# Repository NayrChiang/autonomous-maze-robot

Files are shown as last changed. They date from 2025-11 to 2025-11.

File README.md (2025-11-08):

# Autonomous Maze Navigation Robot

A comprehensive autonomous robot system for maze navigation, localization, and block manipulation using Arduino, MATLAB, and probability-based algorithms. This project demonstrates integration of multiple sensors, real-time control, and autonomous decision-making in a complex environment.

## Project Overview

**Course**: MIE444 - Mechatronics  
**Institution**: University of Toronto  
**Term**: Fall 2022

### Objective

Design and build an autonomous robot capable of navigating a maze, localizing its position using probability-based algorithms, avoiding obstacles, detecting blocks, and manipulating objects to complete assigned tasks.

## Key Features

### Multi-Sensor Data Fusion
- **7 Ultrasonic Sensors (HC-SR04)**: Front, left, right, back, and 45° angle sensors for comprehensive obstacle detection
- **2 IR Sensors**: Block detection and floor pattern recognition for localization
- Multi-sample averaging (5 samples per reading) for noise reduction
- Real-time sensor data fusion for robust environment sensing

### Probability-Based Localization
- Monte Carlo localization algorithm in 32×16 grid maze (512 possible locations)
- IR sensor for color tile recognition
- Real-time position tracking with probability distribution updates
- 10% probability threshold for successful localization confirmation
- Heading initialization and correction at block 14 using unique distance patterns

### Autonomous Navigation
- Perfect obstacle avoidance with collision-free navigation
- Four heading directions (W, A, S, D) for 2D IR localization
- Angle correction logic comparing current and previous step sensor readings
- Wall distance thresholds: front (8cm), sides (4cm), back (5cm)
- Fixed path planning for 32 block locations with configurable loading/unloading sequences

### Block Detection and Manipulation
- Ultrasonic sensor scanning sequence (90-100° rotation in 5° increments)
- Detection criteria: Bottom sensor < 50 cm AND absolute difference between front and bottom sensor > 10 cm
- 3D-printed mechanical gripper controlled by two SG90 servo motors
- Joint servo for elevation control, jaw servo for opening/closing
- Pickup and delivery sequences with precise positioning

### MATLAB-Arduino Integration
- Real-time control via Bluetooth (HC-05, 9600 baud)
- Serial command protocol for motor and servo control
- Real-time probability distribution visualization
- Simplified testing and troubleshooting workflow

## Hardware Components

### Microcontrollers
- **Arduino Uno** (2 boards): Separate boards for sensors and motor/servo control

### Sensors
- **7× Ultrasonic Sensors (HC-SR04)**: Obstacle detection at multiple angles
- **2× IR Sensors**: Block detection and floor pattern recognition

### Actuators
- **DC Motors**: With H-bridge (L298N) for omnidirectional movement
- **2× Servo Motors (SG90)**: 
  - Gripper servo: Controls opening/closing (45-90°)
  - Lift servo: Controls elevation (20-140°)
- **Omni Wheels**: For omnidirectional movement

### Communication
- **HC-05 Bluetooth Module**: 9600 baud serial communication

### Chassis
- Custom 3D-printed design with integrated sensor mounts
- Redesigned from 9-inch to 6.5-inch diameter (top layer) for improved sensor accuracy
- Multi-layer assembly for component organization

## Software Architecture

### Arduino Firmware
- **Arduino_for_Sensors.ino**: Sensor data acquisition and processing
- **Arduino_for_Motor_&_Servo.ino**: Motor and servo control
- Serial command protocol for MATLAB communication

### MATLAB Control Algorithms
- **Matlab_Real_ObsAvoid_HeadingInit_LoadDropOffZone.m**: Main control algorithm
- **Matlab_Real_Block_Detection_PickUp.m**: Block detection and manipulation
- **Matlab_Simulator_ObsAvoid_HeadingInit_LoadDropOffZone.m**: Simulation for testing

### Key Algorithms
- Probability-based localization (Monte Carlo methods)
- Obstacle avoidance with angle correction
- Block detection using ultrasonic scanning
- Path planning and navigation

## Technical Implementation

### Sensor Integration
- Multi-sample averaging (5 samples) for noise reduction
- Distance calculation: ping time to distance (0.017 cm/μs)
- Sensor threshold calibration at various maze locations
- Multi-sensor data fusion for comprehensive environment sensing

### Obstacle Avoidance
- Four heading directions defined for 2D IR localization
- Angle correction logic: Comparison of current step (U3) and previous step (U3') side sensor readings
- If U3 < U3': Rotate counterclockwise to correct angle
- If U3 > U3': Rotate clockwise
- Perfect collision-free navigation achieved

### Localization
- Probability distribution initialization: uniform (1/512 per cell)
- Probability updates: Measurement compared with actual color tile map
- Probability threshold: 10% for confirmation of successful localization
- Threshold-based path switching: switches to fixed path when probability > 10%
- Heading management: Updated by adding/subtracting 90° when robot makes turns

### Block Manipulation
- Initial scan: Shifts left and right to check if block is in straight line of sight
- Detailed scan: 90-100° rotation in 5° increments once inside loading zone
- Pickup sequence: Abort rotation → Drive forward → Open and lower gripper → Close and raise
- Delivery: Navigate to unloading zone → Lower lift → Open gripper → Raise lift → Close gripper

## Project Structure

```
autonomous-maze-robot/
├── arduino-code/
│   ├── Arduino_for_Motor_&_Servo/
│   │   └── Arduino_for_Motor_&_Servo.ino
│   └── Arduino_for_Sensors/
│       └── Arduino_for_Sensors.ino
├── matlab-code/
│   ├── Matlab_Real_Block_Detection_PickUp/
│   │   └── Matlab_Real_Block_Detection_PickUp.m
│   ├── Matlab_Real_ObsAvoid_HeadingInit_LoadDropOffZone/
│   │   └── Matlab_Real_ObsAvoid_HeadingInit_LoadDropOffZone.m
│   └── Matlab_Simulator_ObsAvoid_HeadingInit_LoadDropOffZone/
│       └── Matlab_Simulator_ObsAvoid_HeadingInit_LoadDropOffZone.m
├── cad-models/
│   └── Rover 3D CAD Model/
│       ├── Rover.SLDASM
│       ├── Base - 7 in.SLDPRT
│       ├── Second - 7 in.SLDPRT
│       ├── Third - 7 in.SLDPRT
│       ├── Top Layer - 6 in.SLDPRT
│       └── [other component files]
├── MIE444 Project Final Report.pdf
└── README.md
```

## Installation & Setup

### Prerequisites
- Arduino IDE
- MATLAB (with Arduino Support Package)
- HC-05 Bluetooth module
- Required hardware components (see Hardware Components section)

### Hardware Setup
1. Assemble robot chassis according to CAD models
2. Install sensors and actuators
3. Connect Arduino boards and Bluetooth module
4. Power system setup

### Software Setup
1. Install Arduino IDE and required libraries
2. Upload sensor code to Arduino_for_Sensors board
3. Upload motor/servo code to Arduino_for_Motor_&_Servo board
4. Install MATLAB Arduino Support Package
5. Configure Bluetooth connection in MATLAB
6. Run MATLAB control scripts

## Usage

### Running the Robot
1. Power on both Arduino boards
2. Establish Bluetooth connection between MATLAB and HC-05 module
3. Run main MATLAB control script: `Matlab_Real_ObsAvoid_HeadingInit_LoadDropOffZone.m`
4. Monitor probability distribution and sensor readings in real-time
5. Robot will autonomously navigate, localize, and complete tasks

### Simulation
- Use `Matlab_Simulator_ObsAvoid_HeadingInit_LoadDropOffZone.m` for testing algorithms before real robot implementation
- Adjust sensor error settings for proof of concept testing

## Final Results

### Obstacle Avoidance
✅ **Met requirement**: Rover did not need human assistance, no wall collisions, made minor heading adjustments  
⚠️ **Trade-off**: Speed was slow due to accuracy trade-off, unable to complete all tasks within time limit

### Localization
✅ **Tested in demonstration**: Rover started at block 30 with heading ~170°, followed path to loading zone, arrived at block 1 (loading zone) within time constraint

### Block Detection
✅ **Functional**: Trial 2 - Rover placed at exterior of loading zone (block 17), successfully detected load at center of block 1

### Block Manipulation
⚠️ **Limited**: Detection logic functional, but pickup/delivery failed due to gripper design limitations:
- Insufficient torque (single 12V battery)
- Weak connection (press-fit enlarged after use)
- Size limitations (2.64 inches jaw distance)
- Motor drift during approach

## Key Achievements

- Successfully integrated 9 sensors (7 ultrasonic + 2 IR) with multi-sample averaging
- Implemented probability-based localization algorithm (Monte Carlo) with 10% threshold
- Developed autonomous navigation system with perfect obstacle avoidance
- Designed angle correction logic for accurate localization
- Achieved reliable block detection using ultrasonic sensor scanning
- Integrated MATLAB-Arduino system via Bluetooth for real-time control
- Implemented fixed path planning system for 32 block locations
- Successfully demonstrated localization and navigation in competition
- Designed and fabricated complete robot chassis using SolidWorks CAD
- Redesigned rover for improved sensor accuracy and performance

## Lessons Learned

- **Time Management**: Better allocation needed for rover design, sensor adjustment, and code integration
- **Gripper Design**: Increase size for tolerance, individual power supply for servos, more reliable connection method
- **Code Organization**: Version control (GitHub) would help with code merging and communication
- **Rover Design**: Initial 9-inch diameter had sensors too close to walls; redesign to 6.5-inch improved performance
- **Bluetooth Implementation**: Significant achievement - simplified testing and enabled simultaneous MATLAB/Arduino testing

## License

This project is licensed under the Apache License 2.0 - see the [LICENSE](LICENSE) file for details.

## Acknowledgments

- MIE444 course instructors and TAs
- University of Toronto for providing resources and facilities
- Team members who contributed to the project

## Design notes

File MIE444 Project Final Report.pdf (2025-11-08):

# MIE444 Rover Project Final Report

Chen Hsin Chiang 1003888484 Jeongwoong Choi 1004942743 Lijin Yu 1004720901
Yunxiang Zhang 1005085765

December 15, 2022

Department of Mechanical and Industrial Engineering Faculty of Applied Science and Engineering University of Toronto

1. Executive Summary | 1
2. Detailed Rover Control Strategy | 2
2.1. Obstacle Avoidance Strategy | 2
2.2. Localization & Navigation Strategy | 6
2.3. Block Delivery Strategy | 9
2.4. Integration | 11
3. Final Results | 14
3.1. Obstacle Avoidance | 14
3.2. Localization | 14
3.3. Pick-up & Delivery of the Load | 15
3.4. Integration | 15
4. Discussion | 16

## 1. Executive Summary

In the first Milestone, the team implemented a simple obstacle avoidance technique to turn the rover towards the side with the greatest distance. However, the team discovered that localization required the rover to travel straight. Therefore, obstacle avoidance logic was improved.

By Milestone 3, the rover was able to avoid obstacles, travel a straight path, correct heading and localize in a single trial. It would update its heading correctly after reaching the 4-way intersection. Next, it was able to recognize its location based on the localization logic. Using the localization algorithm, the rover followed pre-written paths to the loading/unloading zone. On one hand, the rover was able to avoid obstacles with perfection, on the other hand, the rover was unable to complete all the tasks within the required time.

In the second trial, the team only demonstrated the load-finding and pick-up functions. With the initial placement of the rover at the exterior of the loading zone, the rover was able to traverse into the loading zone with minor help and detect the load. Following the detection of the load, the rover adjusts its position to pick up the load. However, due to the poor design of the gripper mechanism, it was unable to lift the load. Based on the observed movements of the servo motors, the gripper was outputting the right commands. With the appropriate servo motor selection and enough power supply, the gripper would work as intended.

For the final reflection, the most significant area of improvement was time management. Because of poor time allocation, many deliverables were rushed at the last minute. For instance, rover & gripper design, sensor adjustment and tuning, and integration of the rover’s code.

Video footage of Milestone 3 can be viewed from the link below: https://drive.google.com/file/d/18nUjuD-q-UtoxJ-DPNPjeCtA-5GGfJnk/view?usp=share_link (https://drive.google.com/file/d/18nUjuD-q-UtoxJ-DPNPjeCtA-5GGfJnk/view?usp=share_link)

## 2. Detailed Rover Control Strategy

2.1. Obstacle Avoidance Strategy

Since only four heading directions (W, A, S, D) were defined in the 2D IR localization algorithm, it was crucial that the robot travelled in a relatively straight path while avoiding obstacles. If the rover regularly travelled along the diagonal direction, the probability matrix did not update accurately, and the localization did not work well. Therefore, one of the major objectives for the final obstacle avoidance strategy was to ensure travelling straight.

For obstacle avoidance, SimMer was first utilized for proof of concept: The team first conducted simulations with lower sensor error settings to ensure the validity of the logic. Once all obstacle avoidance objectives were achieved, the team then converted codes to be compatible with Arduino and Bluetooth and tested them in the real maze. To achieve travelling straight, the team first attempted the below sensor setup:

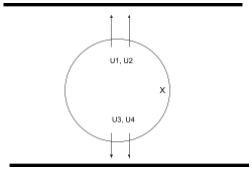
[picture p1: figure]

Figure 1: Sensor Configuration for Obsolete Approach

It was conjectured that when the rover travelled in a straight path, the difference in reading between U1&U2 and U3&U4 would be small. Thus, if the difference in reading on either side exceeded a threshold, we could adjust the rover by rotating itself until the difference values are within the threshold. However, this method did not work well, even in the simulation, due to inaccuracies in sensor measurements. When the sensors were at an angle from the wall, they often returned inaccurate distances, (could be higher or lower than expected), which made the difference calculations unreliable. The team could not find a single threshold value that accounted for the inaccuracies while keeping the robot travelling straight. Thus, this approach was abandoned.

The other approach, which was included in the eventual obstacle avoidance strategy, chose the side sensor that returned a smaller reading at the current step (U3) and compared the reading with the one at the previous step (U3’). If U3 < U3’ (as illustrated in Figure 3), the robot would rotate a small angle counterclockwise to correct the angle and compensate for the deviation. If U3 > U3’, the rover would rotate clockwise.

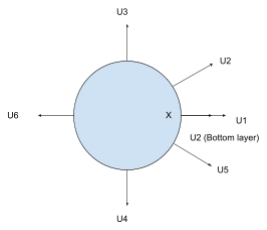
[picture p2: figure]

Figure 2. Final Sensor Configuration of the Rover

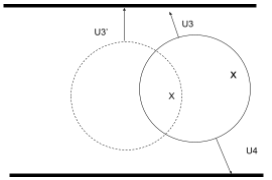
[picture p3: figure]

Figure 3. Distance Comparison between the Current and the Previous Step

Once the implementation of the above angle correction logic in SimMer was successful, the team integrated the code with the obstacle avoidance strategy used in Milestone 1. The final strategy can be summarized in the flowcharts below.

As the last step of simulation code testing, the strategy was packaged into MATLAB functions and called during each loop of the main function. At this point, obstacle avoidance was running in an infinite loop. This strategy still performed well after the code was converted from the simulation to the real robot application. The team only needed to modify the sensor threshold values based on the real maze, which determined if the rover was too close to the wall. To establish all sensor threshold values, the team took ultrasonic sensor measurements at various locations in the maze. This obstacle avoidance strategy allowed the rover to run indefinitely without hitting a wall.

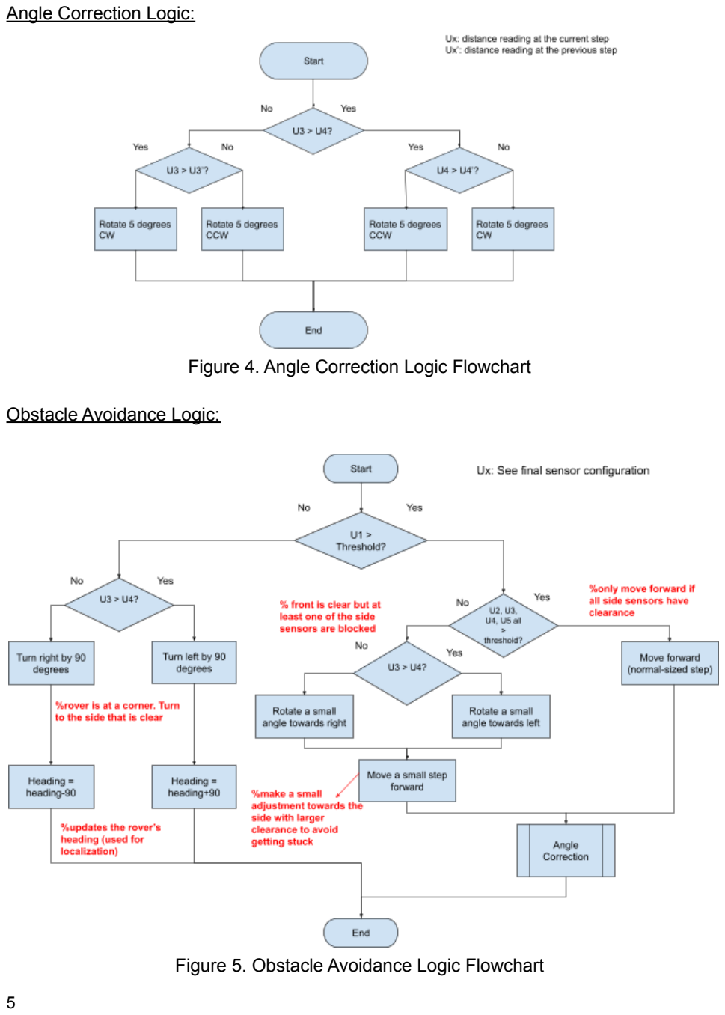
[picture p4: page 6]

Angle Correction Logic:

Figure 4. Angle Correction Logic Flowchart

Obstacle Avoidance Logic:

Figure 5. Obstacle Avoidance Logic Flowchart

2.2. Localization & Navigation Strategy

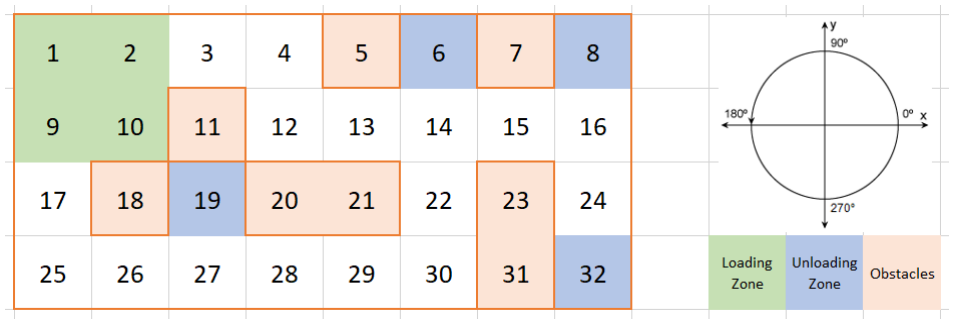
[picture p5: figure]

Figure 6. Numbering Convention of the Maze

To localize the rover, the team used an IR sensor to recognize the colour tiles and implemented a modified version of the sample code. Whenever a measurement was taken, it was compared with the actual colour tile map. Then, the code updated the localization probability matrix. Initially, there would be various locations that matched the sequence of the tiles. However, as the rover travelled, the chance of getting the specific sequence from the measured tiles decreased. With enough measurements, there would only be one location that had a high probability (Figure 7).

By trial and error, the team determined that a probability of 10% was a reasonable threshold value for confirmation of successful localization. If the threshold value was higher, it would take too long before the rover started travelling toward the loading zone. If the threshold value was lower, the localization would lack accuracy.

Once the highest probability within the matrix reached 10%, the rover would begin using the localization data for travelling to the loading or drop-off zone. The index of the highest probability in the probability matrix was converted to a block number. Then, using the block number, the rover extracted the destination heading from a predefined array to correctly navigate to either the loading or drop-off zone. The predefined array consisted of 32 elements that corresponded to each block. Each element had two headings: one for the robot to navigate to the loading zone, and another to the drop-off zone.

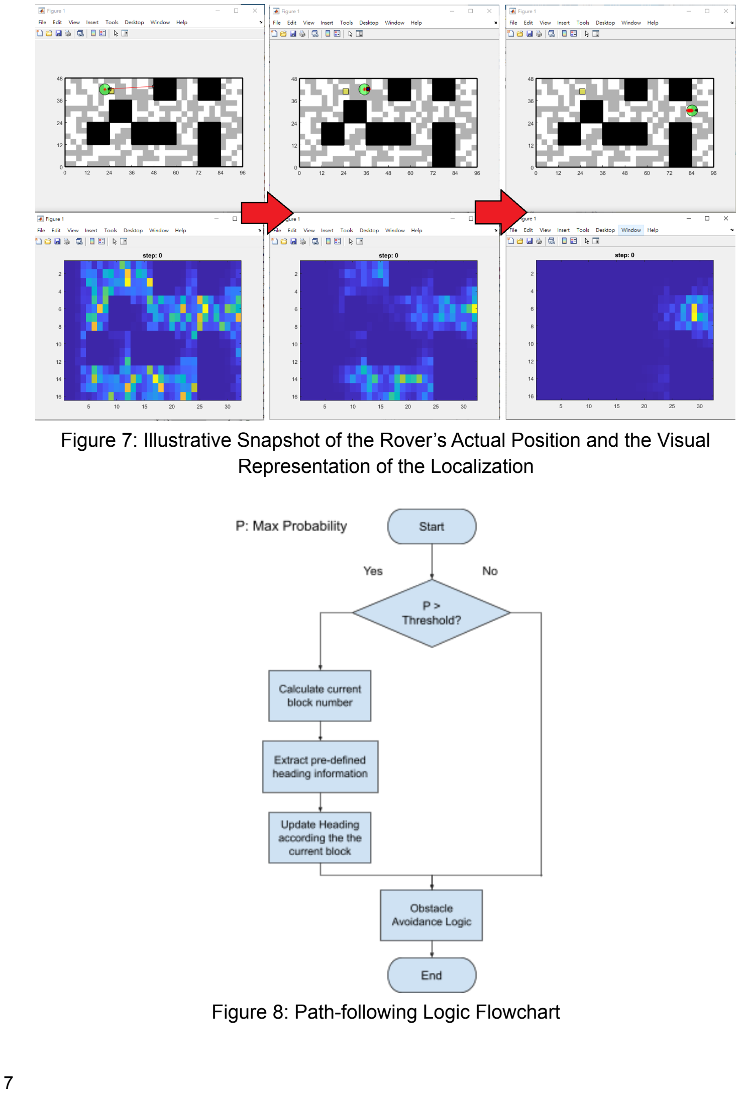
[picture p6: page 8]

Figure 7: Illustrative Snapshot of the Rover’s Actual Position and the Visual Representation of the Localization

Figure 8: Path-following Logic Flowchart

The team also discovered that in order for the localization algorithm to work well, the heading of the rover needed to match the code setup: If the actual rover heading was different from the algorithm’s heading parameter, the probability matrix would shift and update in an incorrect direction whenever the rover moved. Consequently, the localization would not be accurate.

Since localization and fixed-path logics were more integral to completing the overall task, they were developed assuming that the rover would always start in a heading that matched the code. After developing a functional localization strategy, the team implemented a heading correction function. This function used the 4-way clearance at block 14 because it had a unique set of distances. When the rover entered block 14, the ultrasonic sensors would provide a set of distances that match the predefined distance requirement and would update its heading. Once the heading was updated, the rover would turn to the side that was the closest to the loading zone to speed up the testing trial.

During localization, obstacle avoidance logic was still being used. Whenever the robot made a turn, the heading would be updated by adding or subtracting 90° (Figure 9); when travelling along a corridor, the angle correction function ensured travelling straight, thus there were no accidental turns that distorted the heading again.

One last problem was that the highest probability fluctuated around the threshold in rare instances. For the few steps with their probability dropping below 10%, the rover could still rely on obstacle avoidance to travel toward the destination until the probability reached 10% again. This was because the team observed that the obstacle avoidance logic produced a very similar set of headings compared to the pre-defined desired headings once the highest probability first reached 10%.

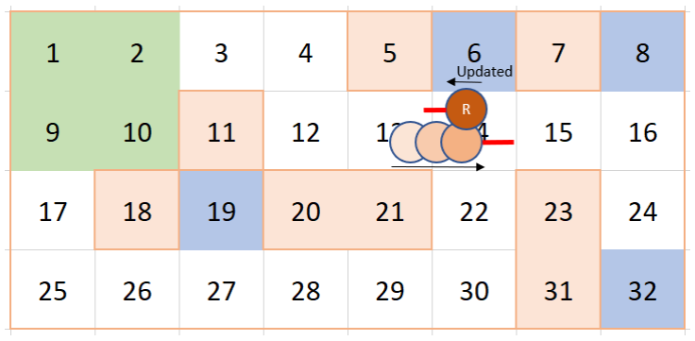
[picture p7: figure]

Figure 9. Change of Heading at 4-Way Crossing

For navigating to the loading zone, once the rover identified that it was in either block 3 or 17, it would stop when it was at the edge of the loading zone (i.e. the exterior perimeter), displayed a message to indicate arrival, and began locating and collecting the load. For navigating to the unloading zone, the rover would head into the unloading zone and stop with just enough room to place the load down.

2.3. Block Delivery Strategy

The block pick-up mechanism used on this rover was a 3D-printed mechanical gripper which was controlled by two SG90 servo motors: one controlled the elevation of the gripper which connected the gripper to the chassis and would be referred to as the joint, and the other controlled the opening/ closing of the jaw.

During the initial stages of the rover’s operation, before it reached the loading zone, the gripper would be closed and raised to 90°. This design was to allow the same navigation strategy after the load was picked up and the rover navigated toward the unloading zone. Moreover, the raised gripper allowed the load-detecting ultrasonic sensor to be interference-free.

The team’s first attempt at the load-finding technique was to only utilize shifting since the motor output low drift/error. The first method consisted of having the robot face block 10 from the beginning and “scan” the entire loading zone by shifting into the loading zone either from block 3 or 17. This method was implemented through the simulator and performed well.

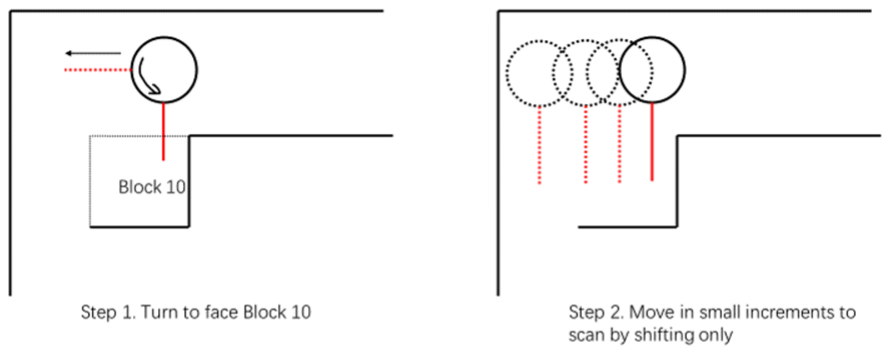
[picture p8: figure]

Figure 10. Block-finding Method 1

However, for this technique, improvements were needed due to physical limitations. If the load was placed in the center of blocks 1 or 2 (or 9), the rover would not be able to detect the load when it shifted in from block 3 (or 7, respectively) due to its size (Figure 8), and it would run over the block.

Design-wise, the load-detection sensor demanded a measuring distance greater than the rated distance of the IR sensor (same location at U2). Therefore, for the final load-detection technique, the team decided to use an ultrasonic sensor instead and implement a more detailed scanning sequence for load-detection.

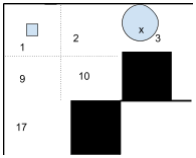
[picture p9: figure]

Figure 11. Limitation of Method One

The scanning sequence began after the rover arrived at either block 3 or 17. The rover would activate the front-facing ultrasonic sensor mounted below the gripper. Then, it would perform an initial scan to check if the block was in its straight line of sight by shifting left and right. If the block was not detected, the rover would perform a 90° turn to face block 10. Then, it would shift inside the loading zone (either block 9 or 2). Once the rover entered the loading zone, it would perform a 90-100° scan in 5° increments.

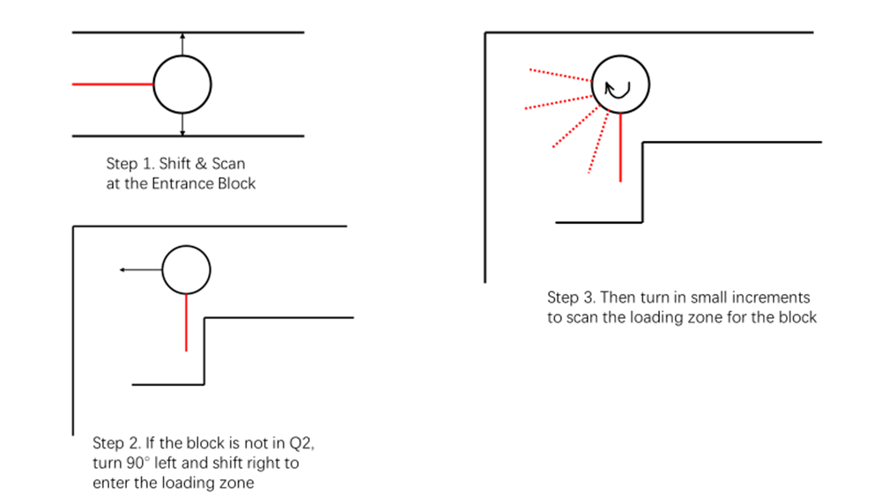
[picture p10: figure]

Figure 12. Block-finding Method Two

When the ultrasonic sensor detected the block (i.e. when the bottom sensor reading was less than 50 cm and the absolute difference between the front and bottom sensor was greater than 10 cm), the rover would abort further rotations and drive forward until the load was within the operating range of the gripper. The rover would then open and lower the gripper, place the block between the two clamps, and close and raise it back to 90°. After the load was picked up and stored in the rover, the rover would navigate to the unloading zone using the same technique when it navigated to the loading zone.

2.4. Integration

The complete logic for the project could be summarized using a flowchart in Figure 13. Fundamentally, each individual task ( ie. heading initialization, obstacle avoidance, localization, travelling to defined destinations, and load detection & collection) was all packaged into MATLAB functions and called in sequence within an infinite while loop.

The logic can be summarized as the following:
1. Before reaching the 4-way intersection, the rover only executed obstacle avoidance logic.
2. Once the rover reached the 4-way intersection, it executed the heading initialization logic, which corrected the heading and commanded the rover to turn toward the closest side of the loading zone. The probability matrix of the localization was also initialized. After this, the heading initialization would be skipped in subsequent loops.
3. The rover executed localization and obstacle avoidance.
4. If an element in the probability matrix reached 10%, the rover would begin travelling toward the loading zone. If the highest probability subsequently dropped below 10%, path-following logic would be temporarily bypassed until the highest probability reached 10% again (section 2.2).
5. Once the rover reached the loading zone (either from block 3 or 17), path-following and obstacle avoidance logic would be bypassed during load detention and collection.
6. The rover would execute load detection and collection. Upon completion, this function would be bypassed in future loops.
7. The rover executed path-following and obstacle avoidance logic while travelling toward the unloading zone.
8. Once it reached the predefined unloading location, the load was gently placed on the floor and the entire code terminated.
* Obstacle avoidance and localization were mostly running unless otherwise specified.

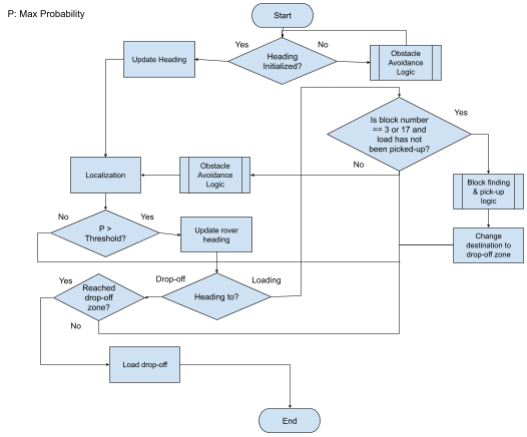
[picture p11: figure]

Figure 13. Overall Integration Logic Flowchart

Finally, it is worth noting that the team did not fully integrate the flowchart. Specifically, the team did not have time to incorporate steps 6 and 8 with the rest of the operations. For Milestone 3, steps 6 and 8 were demonstrated individually; for the actual trial, after the rover reached the loading zone, it directly proceeded to execute travelling to the unloading zone. This will be discussed further in section 3.

## 3. Final Results

3.1. Obstacle Avoidance

The overall performance of the rover’s obstacle avoidance met the requirement: the rover did not need any human assistance to travel through the maze and it did not collide with the maze walls. The rover was also able to make minor adjustments to its heading in order to maintain a rather straight path. However, the trade-off for accuracy was speed. The speed of the rover was slow, and the rover was unable to complete all tasks within the time limit.

3.2. Localization

Localization was tested in Trial 1 of Milestone 3. As shown below in Figure 14, the rover started at block 30 with a heading at about 170° and followed the path as sketched with the red line to the 4-way crossing, where it successfully updated its heading. The rover then adjusted its heading to 180° and moved toward the loading zone. Since the team was unable to integrate the load-detection and collection functions, the team set the arrival at block 1 as a trigger to print “I am at the loading zone!” in the MATLAB command window to indicate that the rover had arrived at the loading zone. The trial terminated after the rover reached the loading zone due to a time constraint of 10 minutes.

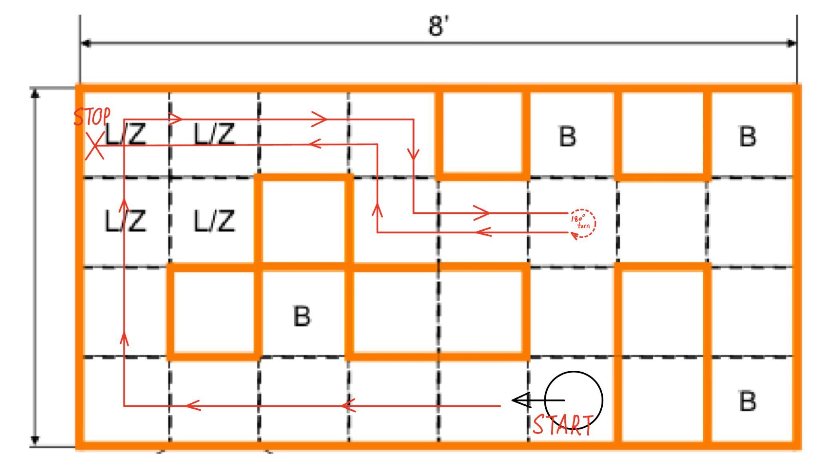
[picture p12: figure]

Figure 14. Rover Route for Milestone 3 Trial 1

3.3. Pick-up & Delivery of the Load

The team focused on the load detection and pick-up functions during Trial 2 of Milestone 3. The team skipped the localization section, placed the rover at the exterior of the loading zone (at block 17, figure 6), and activated the block detection algorithm.

The rover first scanned and determined that the load was not in block 9. Then, it entered the loading zone and successfully detected the load, which was located at the center of block 1. Finally, it travelled forward and activated the series of gripper
commands to pick up the block.

Overall, the load detection logic was functional as the rover successfully identified the load. However, load pick-up & drop-off failed due to poor gripper control & design. When the rover entered the loading zone, some manual assistance was required to correct inaccurate motor movements and avoid wall collisions. The gripper failed to pick up the load due to jaw misalignment and a lack of torque at the joint. Specifically, as the rover moved forward to the load, motor inaccuracies caused drifting with respect to the load. The gripper lowered to roughly the correct position but the team had to manually place the load in the center of the jaw to secure it. For the load drop-off, the gripper fell off the rover due to a weak connection between the joint servo and the gripper base. Despite this, the gripper was able to open and close at the appropriate time according to
MATLAB commands. Lastly, the team did not demonstrate delivering the load to the drop-off location due to time constraints. Delivery was illustrated in the full-run video that demonstrated the robot traversing to both the loading and unloading zones using localization.
3.4. Integration

The team treated the gripper design as an independent section, and several issues, which were identified very late in the project, could not be fixed: While gripper testing succeeded on its own, the team did not account for the distribution of battery power and gripper mounting mechanism. This led to insufficient torque for load pickup and a weak connection between the gripper and the rover.

The team experienced difficulties integrating all the MATLAB code to match the full sequence of the flowchart (figure 13). Specifically, there was confusion in compiling various sections due to unorganized version control. For instance, because the use of functions and documentaries was not stressed at the beginning, various versions of obstacle avoidance code existed, which caused confusion and required much time to troubleshoot. Consequently, the team could not integrate load detection and pickup into the final version of the code.

Overall, the integration of various components of this project was considered poor. Several means to improve integration are discussed in section 4.

## 4. Discussion

There were many areas of improvement, but some of the major challenges the team encountered were the design of the gripper and code integration of the entire operation.

As discussed, the gripper could have been better designed. The team tested the gripper the day before Milestone 3, thus, unable to adjust and iterate an improved model. At the beginning of the project, two SG90 servo motors were given for gripper operation. However, the team did not consider the power supply for these servo motors until they were installed. Because the team used a single 12V battery to power all motors, Arduino boards, and sensors, the power that the servo motors drew were insufficient to exert a strong grip on the load and lift it.

Initially, the gripper was installed using a press fit, as shown below in Figure 15. However, due to the low precision of 3D printing, the hole was not properly fitted and it enlarged after a few uses. Even after the team attached the gripper using the fitting provided by the factory, the required holding force of the load exceeded the fittings, hence, it fell off the joint motor. A more reliable connection method would be designing a plastic gear that has a slot to hold a smaller metallic gear. Since the plastic gear had larger teeth, a smaller metallic gear would be required to fully transmit the torque from the servo motor as well as keep the gripper firmly attached to the motor.

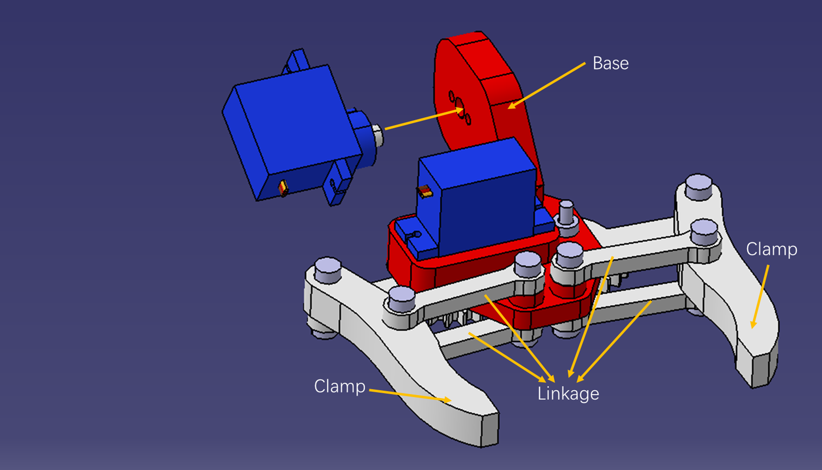
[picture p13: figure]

Figure 15. CAD Drawing of the Gripper

Moreover, the size of the jaw was too small. When designing the CAD model of the gripper, the distance between the two clamps of the gripper was 2.64 inches. However, the built-up errors during the rover’s movement and inaccuracies of the sensors left very little clearance between the load and the clamps.

If the team were to improve the design of the gripper, the first thing would be to increase the size of the gripper to allow more tolerance for error. Moreover, it would be ideal to have an individual power supply for the servo motors, so that it can be guaranteed that the servos would be able to provide sufficient torque for load pick-up. Lastly, the team should allocate more time to the gripper in the event that a re-design is required.

The team also had to rebuild the rover after a challenging development for Milestone 1. The first rover had a diameter of 9 inches so the sensors were too close to the wall. This resulted in the sensors’ frequent incorrect distance measurements, which directed the rover into the maze wall. The team barely made obstacle avoidance work by moving the sensor as inward as possible. The team learnt from this experience and re-designed the rover entirely.

After Milestone 1, the re-designed rover was smaller, with a diameter of 6.5 in for the top sensor layer and 7.5 in for the bottom motor layer, and performed obstacle avoidance much better. The logic and programming behind obstacle avoidance allowed the rover to navigate within the maze collision-free to any obstacle and follow rather straight paths. The newly improved movement algorithm also allowed the sample localization code to work properly and output very accurate predictions of its actual location.

For the coding aspect, the final code integration took more time than expected due to inefficient code organization. Overall, tools like GitHub could help with the merging of codes for this project. Also, better communication could have given the team an upper hand in realizing the inconsistency early on. In addition, the delay between each rover movement was extremely long compared to SimMer, and this caused the Milestone 3 trials to run over the time limit. If given more time, the team would investigate the causes and hopefully resolve this incompetency.

There were also areas deserving praise, such as the obstacle avoidance and implementation of the Bluetooth module after Milestone 1.

Reviewing our RFP, the final obstacle avoidance logic achieved most of the related functions and objectives, namely navigating through a walled maze without collision and minimizing human interactions during the task execution. The angle correction logic also facilitated the success of localization and travelling to designated locations.
Lastly, the implementation of Bluetooth was a significant achievement because it greatly simplified rover testing and troubleshooting. The Bluetooth connection allowed the team to avoid conflicting with other teams’ USB cables, which was convenient because the team could continue testing even when multiple teams crowded the maze area. Also, the team could simultaneously test MATLAB and Arduino codes without changing the

COM ports, which was beneficial as the team could more easily troubleshoot sensor readings during Milestone 2.

Overall, the team members had increased their overall capacity to stress and work under pressure. The team also realized the importance of time management to alleviate the workload in more manageable terms. Moreover, the team gained the ability to predict potential problems and accounted for them during the design phase. On the technical side, the team gained a deeper understanding of mechatronic components, including power protection, Bluetooth connection, wire management, sensor allocation, CAD design, and motor control. Finally, each member learned the importance of version control in coding.

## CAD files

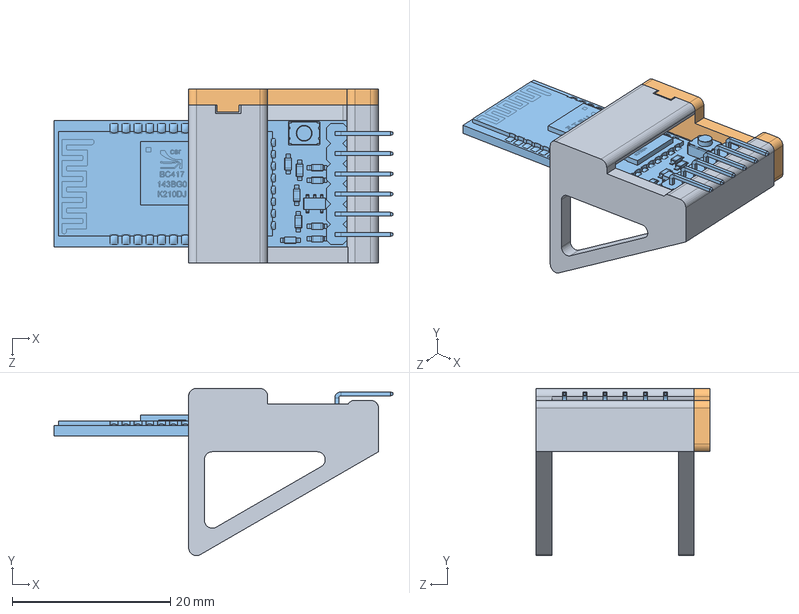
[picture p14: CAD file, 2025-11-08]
cad-models/Rover 3D CAD Model/BT Asm.SLDASM
42.8 x 21.1 x 22.0 mm
BT Holder
BT Cover
Bluetooth Module HC-05

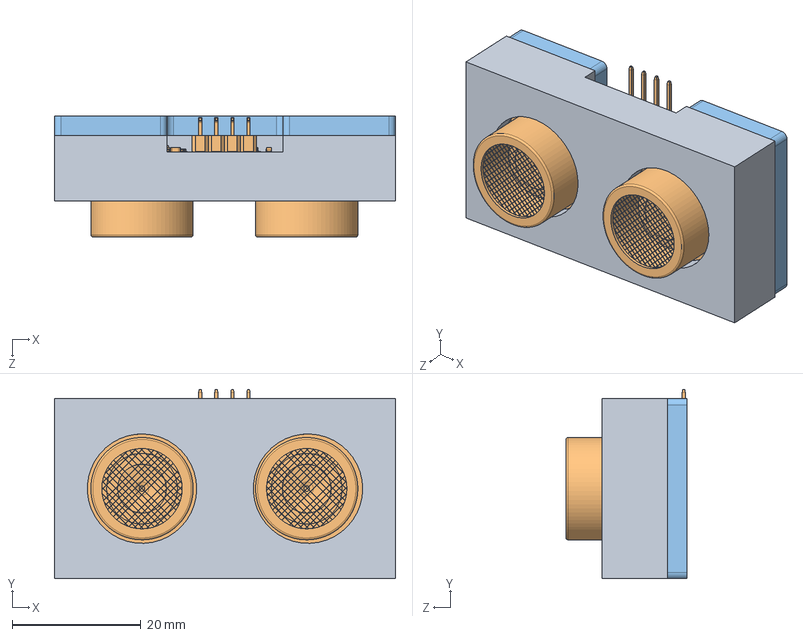
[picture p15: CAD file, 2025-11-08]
cad-models/Rover 3D CAD Model/Ultra_dist_asm.SLDASM
53.0 x 29.5 x 18.8 mm
Ultrasonic_load
Ultrasonic Sensor HC-SR04
Ultra Lid

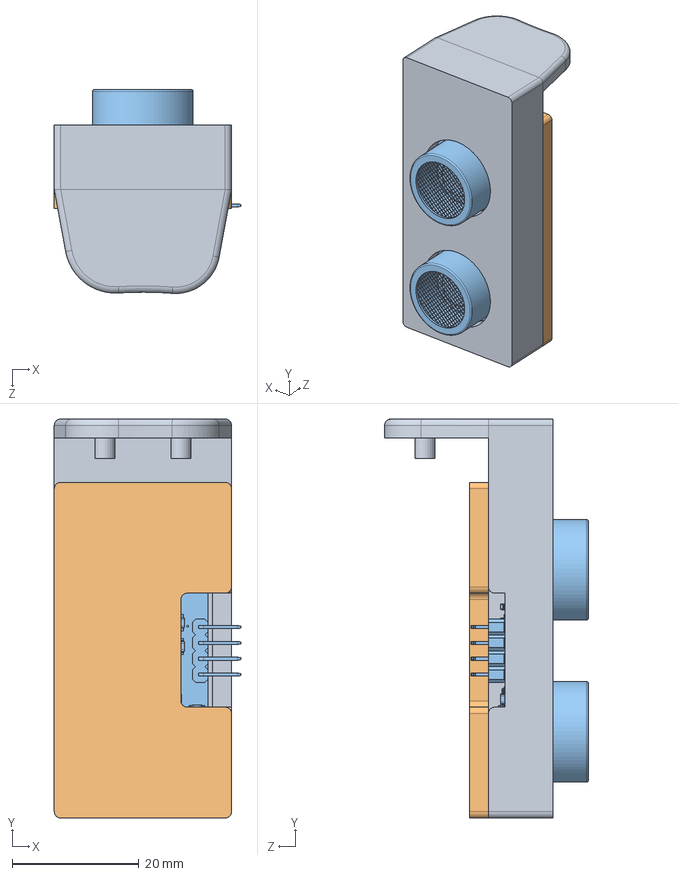
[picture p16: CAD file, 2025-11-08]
cad-models/Rover 3D CAD Model/Ultra H Asm.SLDASM
29.5 x 63.0 x 32.2 mm
Ultra Casing
Ultra Lid
Ultrasonic Sensor HC-SR04

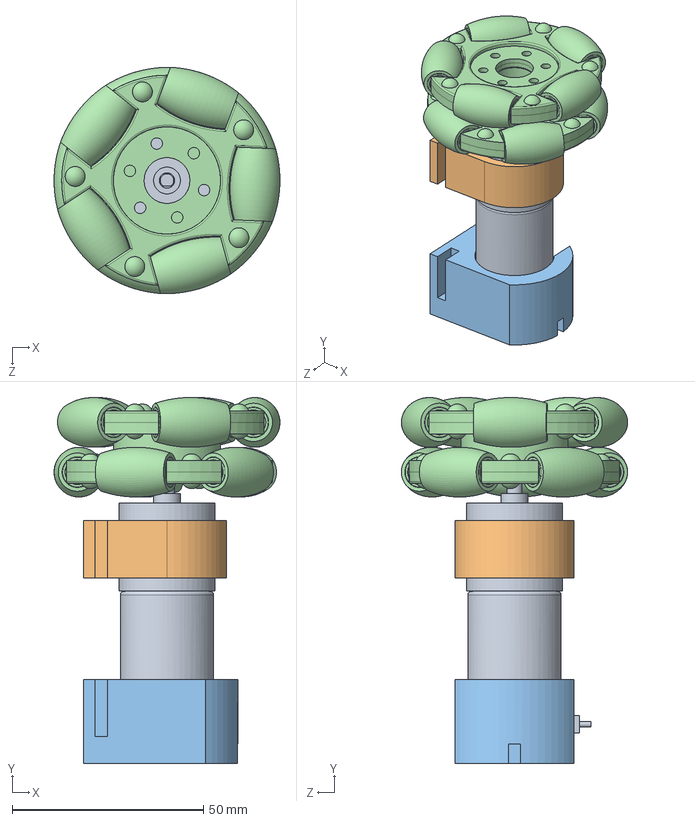
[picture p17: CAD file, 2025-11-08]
cad-models/Rover 3D CAD Model/Motor Asm.SLDASM
59.0 x 95.6 x 59.1 mm
DC Motor
Motor holder front
Motor holder rear
Omni Wheel

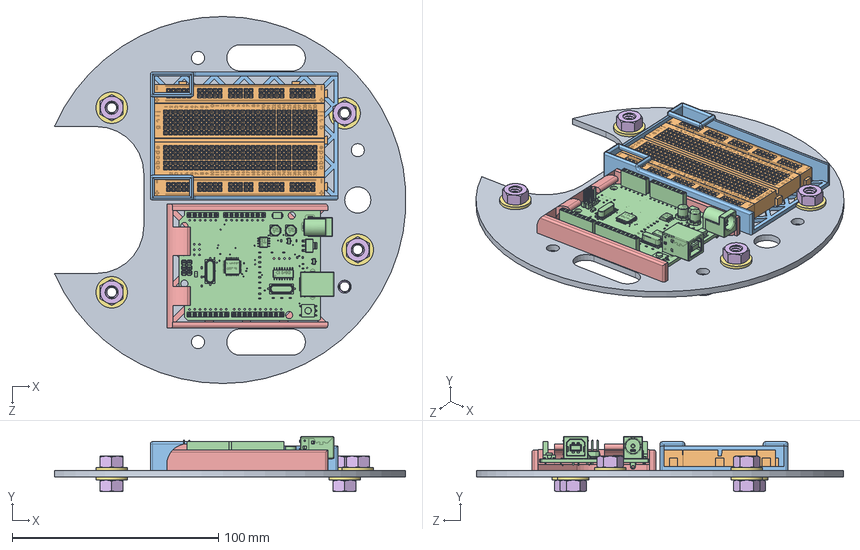
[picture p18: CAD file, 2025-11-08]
cad-models/Rover 3D CAD Model/Third Lay.SLDASM
170.2 x 26.8 x 177.8 mm
Third - 7 in
BreadBoard small
Breadboard small holder
Assembly Arduino Uno R3
Arduino Holder
Hex Nut 1-4 20 x 8
Washer 1-4 Side x 8

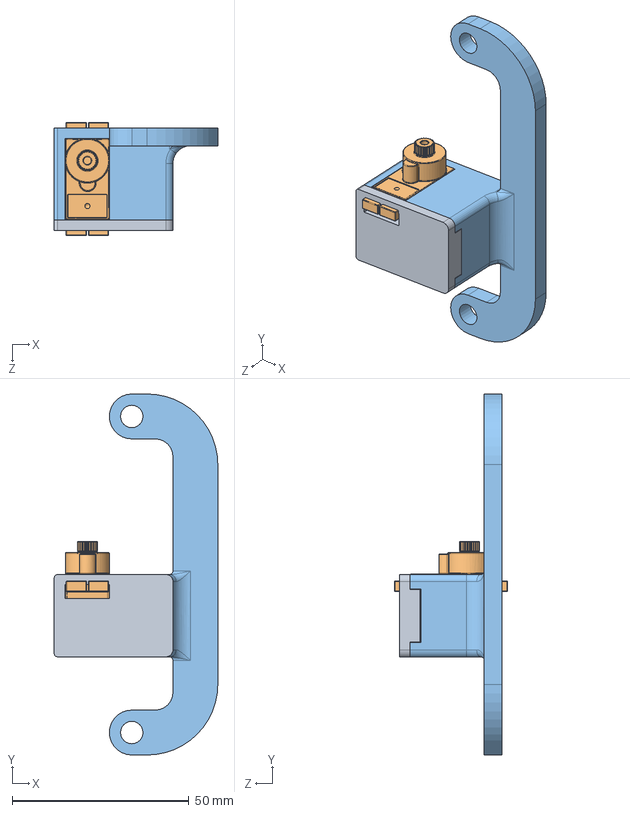
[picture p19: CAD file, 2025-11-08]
cad-models/Rover 3D CAD Model/Servo_asm.SLDASM
46.3 x 102.1 x 32.1 mm
Gripper_Holder_Lid
Servo
Gripper_Holder

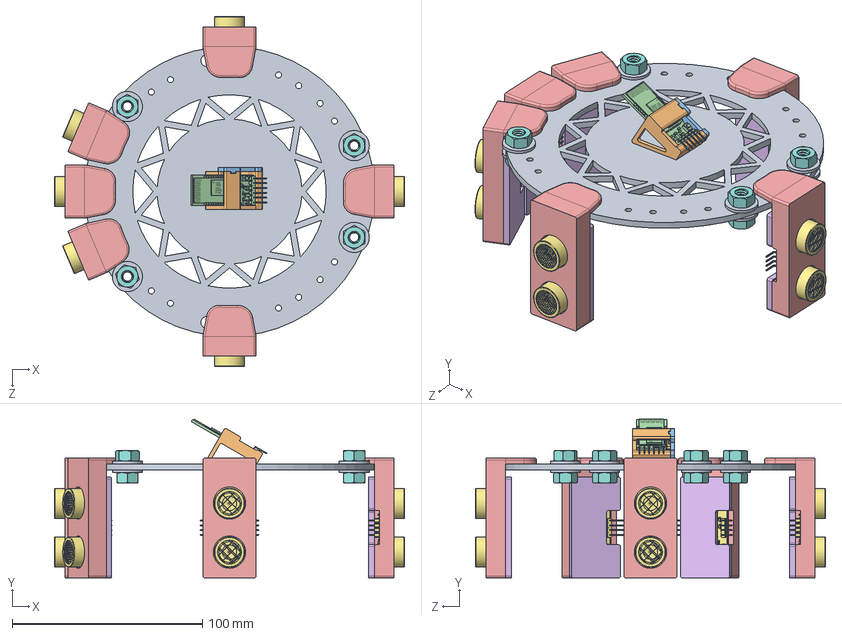
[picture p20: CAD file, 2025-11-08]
cad-models/Rover 3D CAD Model/Top Lay Asm.SLDASM
184.0 x 83.6 x 184.0 mm
Top Layer - 6 in
BT Holder
BT Cover
Bluetooth Module HC-05
Ultra Casing x 6
Ultra Lid x 6
Ultrasonic Sensor HC-SR04 x 6
Hex Nut 1-4 20 x 8
Washer 1-4 Side x 8

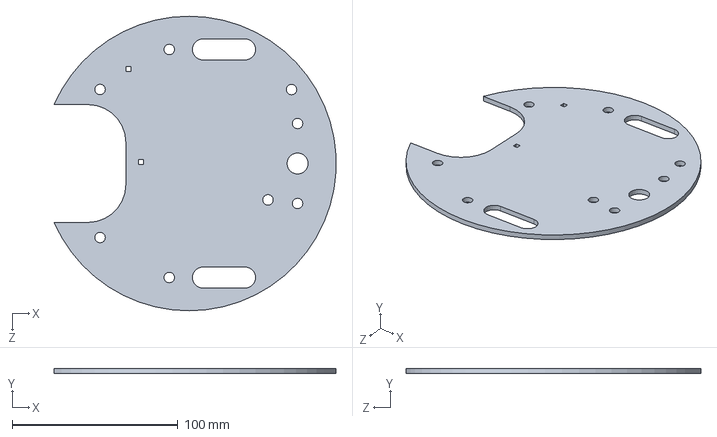
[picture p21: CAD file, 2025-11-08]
cad-models/Rover 3D CAD Model/Second - 7 in.SLDPRT
170.2 x 3.17 x 177.8 mm

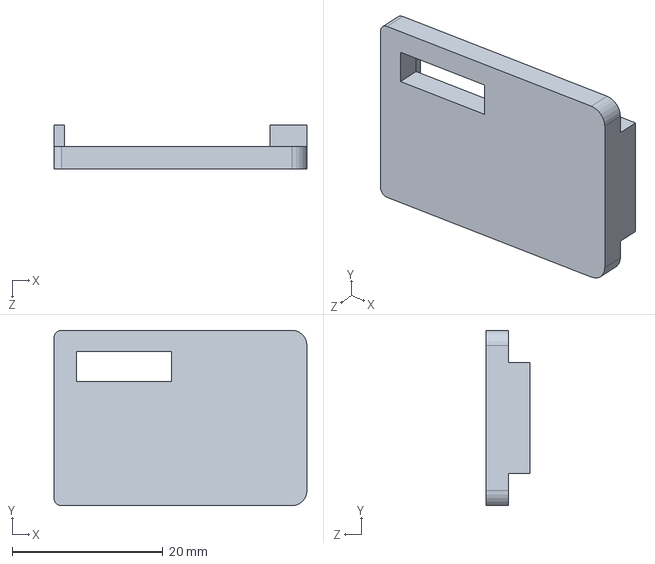
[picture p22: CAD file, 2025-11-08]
cad-models/Rover 3D CAD Model/Gripper_Holder_Lid.SLDPRT
33.6 x 23.3 x 5.90 mm

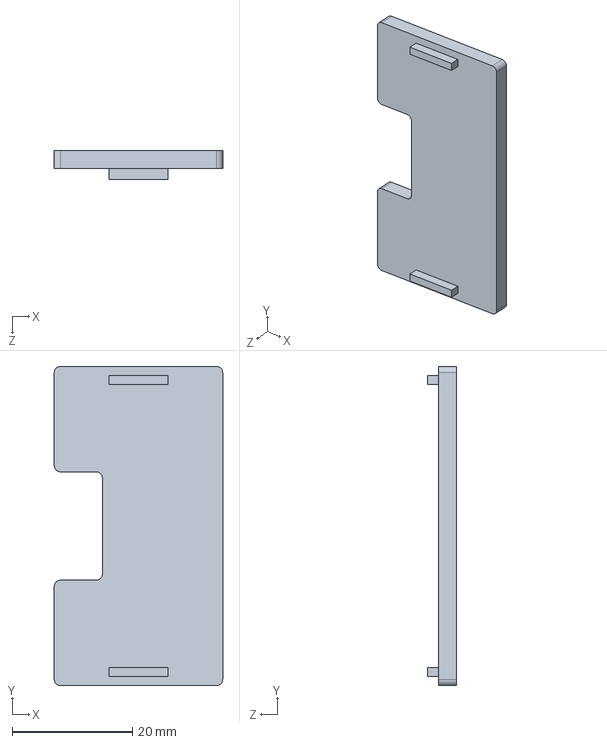
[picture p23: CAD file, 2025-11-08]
cad-models/Rover 3D CAD Model/Ultra Lid.SLDPRT
28.0 x 53.0 x 4.90 mm

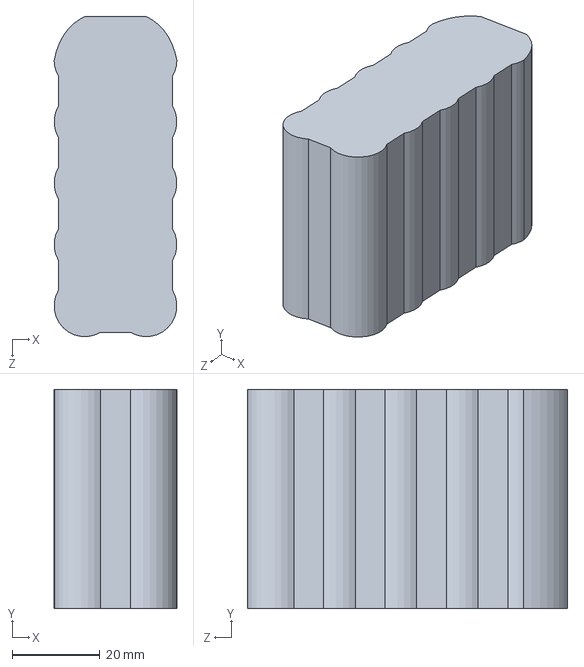
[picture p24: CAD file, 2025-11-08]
cad-models/Rover 3D CAD Model/Battery.SLDPRT
28.0 x 50.0 x 73.0 mm

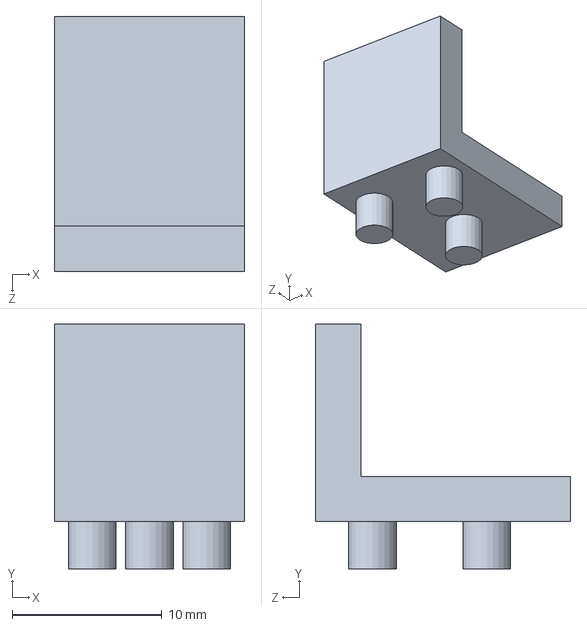
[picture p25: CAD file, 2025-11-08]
cad-models/Rover 3D CAD Model/Battery Holder 2.SLDPRT
12.7 x 16.3 x 17.0 mm

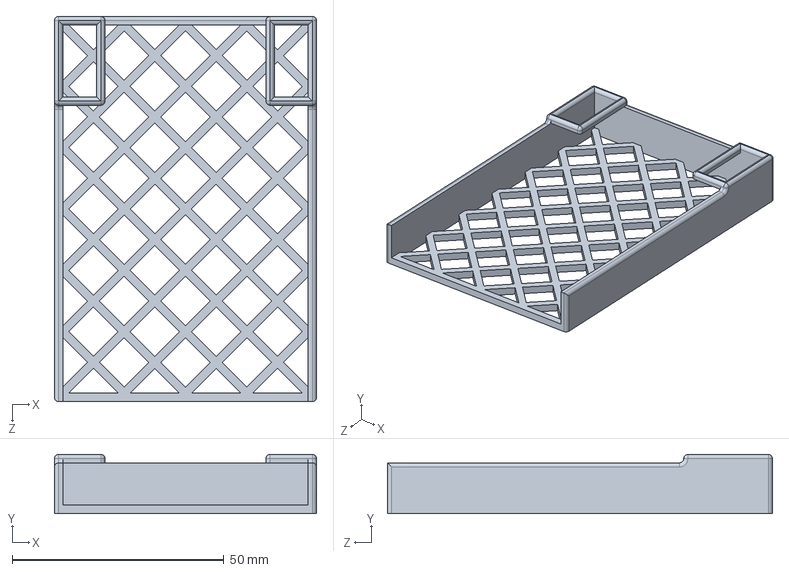
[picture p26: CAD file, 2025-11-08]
cad-models/Rover 3D CAD Model/Breadboard small holder.SLDPRT
62.0 x 14.0 x 91.0 mm

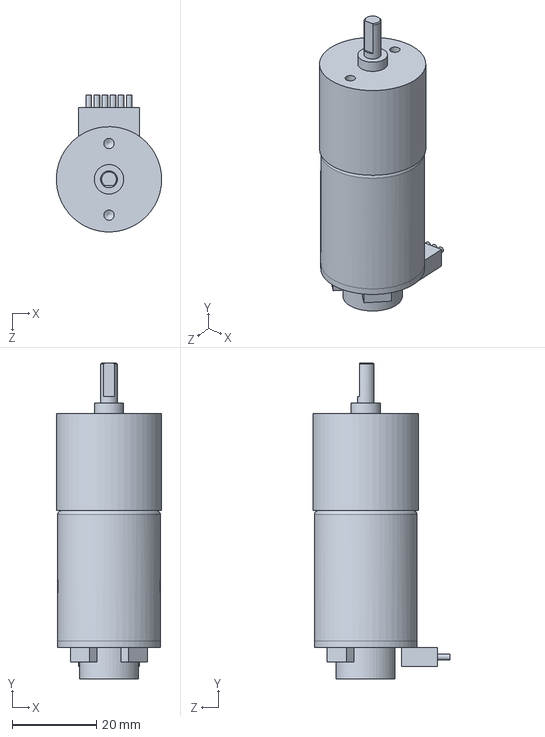
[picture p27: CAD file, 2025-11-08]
cad-models/Rover 3D CAD Model/DC Motor.SLDPRT
25.0 x 75.0 x 32.5 mm

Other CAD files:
cad-models/Rover 3D CAD Model/IR Sensor.SLDPRT
cad-models/Rover 3D CAD Model/IR Sensor Layer.SLDPRT
cad-models/Rover 3D CAD Model/Base - 7 in.SLDPRT
cad-models/Rover 3D CAD Model/Ultrasonic_load.SLDPRT
cad-models/Rover 3D CAD Model/Arduino Holder.SLDPRT
cad-models/Rover 3D CAD Model/BT Cover.SLDPRT
cad-models/Rover 3D CAD Model/BT Holder.SLDPRT
cad-models/Rover 3D CAD Model/Battery Holder.SLDPRT
cad-models/Rover 3D CAD Model/Bluetooth Module HC-05.SLDPRT
cad-models/Rover 3D CAD Model/Gripper_Holder.SLDPRT
cad-models/Rover 3D CAD Model/Hex Nut 1-4 20.SLDPRT
cad-models/Rover 3D CAD Model/L298 Holder.SLDPRT
cad-models/Rover 3D CAD Model/L298N Stepper Motor Driver.SLDPRT
cad-models/Rover 3D CAD Model/Motor holder front.SLDPRT
cad-models/Rover 3D CAD Model/Motor holder rear.SLDPRT
cad-models/Rover 3D CAD Model/Servo.SLDPRT
cad-models/Rover 3D CAD Model/Third - 7 in.SLDPRT
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

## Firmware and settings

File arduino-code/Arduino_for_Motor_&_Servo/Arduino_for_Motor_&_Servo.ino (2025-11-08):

#include <Servo.h>       
Servo servo_grip; 
Servo servo_lift;  

int val = 0;  //holds ascii from serial line
int enA = 11;
int enB = 6;
int in1 = 8;
int in2 = 7;
int in3 = 4;
int in4 = 2;
int in5 = 12;
int in6 = 13;
int pos = 0;

int x;
int frontDist, rightDist, backDist, leftDist;
int maxFrontDist = 7, maxBackDist= 7, maxLeftDist = 7, maxRightDist = 7;

void setup() {
  Serial.begin(9600);
  Serial.println("Rover Uno is alive!");
  // set all the motor control pins to outputs
  pinMode(enA, OUTPUT);
  pinMode(enB, OUTPUT);
  pinMode(in1, OUTPUT);
  pinMode(in2, OUTPUT);
  pinMode(in3, OUTPUT);
  pinMode(in4, OUTPUT);
  pinMode(in5, OUTPUT);
  pinMode(in6, OUTPUT);
  servo_grip.attach(5);
  servo_lift.attach(3);  
}

// Motor Command Functions
void MoveFwd() {
  digitalWrite(in1, HIGH);
  digitalWrite(in2, LOW);
  digitalWrite(in3, HIGH);
  digitalWrite(in4, LOW);
  digitalWrite(in5, HIGH);
  digitalWrite(in6, HIGH);
  analogWrite(enA, 70);
  analogWrite(enB, 70);
}

void MoveBwd() {
  digitalWrite(in1, LOW);
  digitalWrite(in2, HIGH);
  digitalWrite(in3, LOW);
  digitalWrite(in4, HIGH);
  digitalWrite(in5, HIGH);
  digitalWrite(in6, HIGH);
  analogWrite(enA, 70);
  analogWrite(enB, 70);
}

void RotateR() {
  digitalWrite(in1, HIGH);
  digitalWrite(in2, LOW);
  digitalWrite(in3, LOW);
  digitalWrite(in4, HIGH);
  digitalWrite(in5, HIGH);
  digitalWrite(in6, LOW);
  analogWrite(enA, 70);
  analogWrite(enB, 70);
}

void RotateL() {
  digitalWrite(in1, LOW);
  digitalWrite(in2, HIGH);
  digitalWrite(in3, HIGH);
  digitalWrite(in4, LOW);
  digitalWrite(in5, LOW);
  digitalWrite(in6, HIGH);
  analogWrite(enA, 70);
  analogWrite(enB, 70);
}

void Stop() {
  digitalWrite(in1, LOW);
  digitalWrite(in2, LOW);
  digitalWrite(in3, LOW);
  digitalWrite(in4, LOW);
  digitalWrite(in5, LOW);
  digitalWrite(in6, LOW);
  analogWrite(enA, 70);
  analogWrite(enB, 70);
}

void ShiftL() {
  digitalWrite(in1, LOW);
  digitalWrite(in2, HIGH);
  digitalWrite(in3, HIGH);
  digitalWrite(in4, LOW);
  digitalWrite(in5, HIGH);
  digitalWrite(in6, LOW);
  analogWrite(enA, 70);
  analogWrite(enB, 120);
}

void ShiftR() {
  digitalWrite(in1, HIGH);
  digitalWrite(in2, LOW);
  digitalWrite(in3, LOW);
  digitalWrite(in4, HIGH);
  digitalWrite(in5, LOW);
  digitalWrite(in6, HIGH);
  analogWrite(enA, 70);
  analogWrite(enB, 120);
}

void loop(){
  if (Serial.available()){
    val = Serial.read();
    // Motor Command
    if (val == 'a'){
      // rotateL
      RotateL();
      delay(640);
      Stop();     
    }
    else if(val == 'd'){
      //rotateR
      RotateR();
      delay(640);
      Stop();  
    }
    else if(val == 'w'){      
      MoveFwd();
      delay(250);
      Stop();      
    }
    else if(val == 's'){
      MoveBwd();
      delay(60);
      Stop();     
    }
    else if(val == 'e'){
      RotateR();
      delay(90);
      Stop();
    }
    else if(val == 'q'){
      RotateL();
      delay(90);
      Stop();
    }
    else if(val == 'c'){
      ShiftR();
      delay(90);
      Stop();
    }
    else if(val == 'z'){
      ShiftL();
      delay(90);
      Stop();
    }
    else if(val =='f'){
      MoveFwd();
      delay(62.5);
      Stop();
    }

    // Gripper Command
    // Grab
    else if (val == 'g'){      
      delay(500);
      // open gripper
      for (int i = 45; i < 90; i+=1){
        servo_grip.write(i);
      }
      
      delay(500);
      // lower gripper      
      for (int i = 20; i < 140; i+=1){
        servo_lift.write(i);
      }
      
      delay(3000);      
      // close gripper
      for (int i = 90; i > 45; i-=1){
        servo_grip.write(i);
      }
      
      delay(1000);
      // life gripper      
      for (int i = 140; i > 20; i-=1){
        servo_lift.write(i);
      }  
    } 

    // Release
    else if (val == 'r'){      
      delay(500);
      // lower gripper      
      for (int i = 20; i < 120; i+=1){
        servo_lift.write(i);
      }
      
      delay(500);
      // open gripper
      for (int i = 45; i < 90; i+=1){
        servo_grip.write(i);
      }
      
      delay(500);
      // life gripper      
      for (int i = 120; i > 20; i-=1){
        servo_lift.write(i);
      }  
      
      delay(500);      
      // close gripper
      for (int i = 90; i > 45; i-=1){
        servo_grip.write(i);
      }
    } 
  }
  // Holding the gripper
  servo_grip.write(45);  // 45 to 90
  servo_lift.write(20); // 20 to 120
}

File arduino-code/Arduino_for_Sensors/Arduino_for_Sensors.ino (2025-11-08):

#include <NewPing.h>
#define TRIGGER_PIN  7
#define ECHO_PIN1     6
#define ECHO_PIN2     5
#define ECHO_PIN3     4
#define ECHO_PIN4     3
#define ECHO_PIN5     2
#define ECHO_PIN6     8
#define ECHO_PIN7     9
#define MAX_DISTANCE 200
 
int d1, d2, d3, d4, d5, d6, d7;
int IRSensor = A0;
int IRSensor2 = A1;
int green_d = 18;
int blue_d = 8;
int cycle = 0;

String Tot_string;

NewPing sonar1(TRIGGER_PIN, ECHO_PIN1, MAX_DISTANCE);
NewPing sonar2(TRIGGER_PIN, ECHO_PIN2, MAX_DISTANCE);
NewPing sonar3(TRIGGER_PIN, ECHO_PIN3, MAX_DISTANCE);
NewPing sonar4(TRIGGER_PIN, ECHO_PIN4, MAX_DISTANCE);
NewPing sonar5(TRIGGER_PIN, ECHO_PIN5, MAX_DISTANCE);
NewPing sonar6(TRIGGER_PIN, ECHO_PIN6, MAX_DISTANCE);
NewPing sonar7(TRIGGER_PIN, ECHO_PIN7, MAX_DISTANCE);

void setup()
{
  pinMode (IRSensor, INPUT); // sensor pin INPUT
  pinMode (IRSensor2, INPUT); // sensor pin INPUT
  Serial.begin(9600); 
} 
 
void loop()
{
 int count = 0;
 for (int i = 0; i <5; i++){
   // Ignore 0 measurements
   if ( d1 != 0 || d2 != 0 || d3 != 0 || d4 != 0 || d5 != 0 || d6 != 0 || d7 !=0 ){
     delay(30);
     d1 += sonar1.ping_cm();
     delay(30);
     d2 += sonar2.ping_cm();
     delay(30);
     d5 += sonar5.ping_cm();
     delay(30);
     d3 += sonar3.ping_cm();
     delay(30);
     d4 += sonar4.ping_cm();
     delay(30);
     d6 += sonar6.ping_cm();
     delay(30);
     d7 += sonar7.ping_cm();
  
     count += 1;
   }
 
   // Check Intermidate measurements
   // Serial.println("Added measurements");
   // Serial.println(d1);
   // Serial.println(d2);
   // Serial.println(d4);   
 }
  int StatusSense = digitalRead(IRSensor);
  // float v = analogRead(IRSensor2)*0.0048828125;
  // int Bottomdist = 13*pow(v,-1);

  d1 = d1/count;
  d2 = d2/count;
  d3 = d3/count;
  d4 = d4/count;
  d5 = d5/count;
  d6 = d6/count;
  d7 = d7/count; 

  // Send to Matlab
  Tot_string = d1 + String(" ") + d2 + String(" ") + d3 + String(" ") + d4 + String(" ") + d5 + String(" ") + d6 + String(" ") + StatusSense + String(" ") + d7;
  Serial.println(Tot_string);
}
 
